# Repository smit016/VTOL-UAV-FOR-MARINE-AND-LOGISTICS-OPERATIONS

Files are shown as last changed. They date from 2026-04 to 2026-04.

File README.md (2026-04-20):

This report presents the conceptual design and preliminary analysis of a hybrid Vertical
Take-Off and Landing (VTOL) Unmanned Aerial Vehicle (UAV) intended for transportation of
time-sensitive payloads in remote and infrastructure-limited environments. The UAV is
designed to carry a payload of 3–5 kg over a range of up to 100 km while maintaining high
operational flexibility, energy efficiency, and autonomous capability.
A hybrid VTOL configuration is selected to combine the advantages of vertical lift for take-off
and landing with efficient fixed-wing cruise performance. The design process follows a
systematic conceptual design methodology based on the approach proposed by Daniel
Raymer. Key design parameters such as weight estimation, thrust requirements, power
loading, and tail sizing are determined analytically. The design is further validated through
aerodynamic analysis (CFD).

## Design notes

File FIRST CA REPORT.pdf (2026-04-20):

## Conceptual Design and Aerodynamic Analysis of a Hybrid VTOL UAV for Long-Endurance Payload Delivery

Submitted by-:
Smit Panchal
12303271

### ABSTRACT

This report presents the conceptual design and preliminary analysis of a hybrid Vertical Take-Off and Landing (VTOL) Unmanned Aerial Vehicle (UAV) intended for transportation of time-sensitive payloads in remote and infrastructure-limited environments. The UAV is designed to carry a payload of 3–5 kg over a range of up to 100 km while maintaining high operational flexibility, energy efficiency, and autonomous capability.

A hybrid VTOL configuration is selected to combine the advantages of vertical lift for take-off and landing with efficient fixed-wing cruise performance. The design process follows a systematic conceptual design methodology based on the approach proposed by Daniel Raymer. Key design parameters such as weight estimation, thrust requirements, power loading, and tail sizing are determined analytically. The design is further validated through aerodynamic analysis (CFD).

### 1. Introduction

Unmanned Aerial Vehicles (UAVs) have become essential in applications such as surveillance, logistics, agriculture, and disaster response. Based on configuration and flight mechanics, UAVs are broadly classified into:

### 1.1 Types of UAVs

### 1. Fixed-Wing UAVs

- High aerodynamic efficiency
- Long endurance and range
- Require runway or launch systems

### 2. Rotary-Wing UAVs (Multirotors)

- Vertical take-off and landing capability
- Excellent maneuverability
- Limited endurance due to high power consumption

### 3. Hybrid VTOL UAVs

- Combine vertical lift and fixed-wing cruise
- Capable of operating in confined areas
- Offer improved range compared to multirotors

### 3. Problem Statement

The objective is to design a UAV capable of:

- Carrying 3–5 kg payload
- Operating over ~100 km range
- Functioning in remote or infrastructure-limited environments
- Ensuring high reliability and energy efficiency

Why VTOL?

- Eliminates need for runway → critical in remote areas
- Enables deployment in constrained environments
- Improves mission flexibility

Why Hybrid VTOL Configuration?

Pure multirotors are inefficient for long-range missions, while fixed-wing UAVs lack operational flexibility. A hybrid VTOL system provides:

- Efficient cruise (wing-borne lift reduces power demand)
- Vertical take-off capability
- Better endurance compared to multirotors

Why Twin Boom + Pusher Configuration?

- Allows unobstructed airflow for rear propeller
- Provides structural support for tail
- Facilitates payload placement near CG
- Improves stability and control

### 3. METHODOLOGY

Approach

The UAV is designed using a conceptual design methodology based on Daniel Raymer. The design follows a sequential and constraint-based approach, where primary parameters such as weight, wing loading, and thrust requirements are determined from mission requirements.

The procedure adopted is as follows:

1. Estimation of Maximum Take-Off Weight (MTOW) using component build-up method
2. Determination of thrust requirement based on VTOL condition
3. Wing sizing based on stall speed constraint
4. Determination of geometric parameters (span, chord, aspect ratio)
5. Tail sizing using volume coefficient method
6. Estimation of cruise performance and Reynolds number

All calculations were implemented using a Python-based parametric tool to ensure consistency and enable rapid iteration.

WEIGHT AND THRUST ESTIMATION

The MTOW is estimated using a component build-up approach, where known subsystem weights are summed and adjusted using a structural weight fraction. Thrust is determined based on a thrust-to-weight ratio of 2 to ensure safe hover and control during VTOL operation.

Component Category | Notation | Design Value (kg) | % of MTOW
Payload Capacity | W_payload | 5.00 | 28.4%
Energy Source (Battery) | W_batt | 4.00 | 22.8%
Structure & Airframe | W_struct | 5.98 | 34.0%

Thrust Requirements

Propulsion System | W_prop | 1.10 | 6.3%
Avionics & Electronics | W_sys | 1.50 | 8.5%
Maximum Take-Off Weight | MTOW | 17.58 | 100%
Design Parameter | Notation | Unit | Value
Total Weight (Force) | W | N | 172.42
Thrust-to-Weight Ratio | T/W | - | 2.0
Total Thrust Required | T_req | N | 344.84
Number of Motors | N | - | 5
Thrust per Motor | T_motor | N | 68.97

WING SIZING

The wing is sized based on the stall speed constraint to ensure adequate lift generation during low-speed flight and VTOL transition. Wing loading is determined from the lift equation at stall condition, and the wing area is calculated from the estimated weight.

Geometric parameters such as wingspan, chord distribution, and mean aerodynamic chord are obtained using the selected aspect ratio and taper ratio. Cruise velocity is determined from lift equilibrium, and Reynolds number is evaluated to ensure suitability of airfoil selection.

A relatively low wing loading is obtained, which improves low-speed performance and transition stability.

Design Parameter | Symbol | Unit | Value
Design Mass | m | kg | 17.00
Total Weight | W | N | 166.77
Stall Velocity | V_stall | m/s | 14.00
Max Lift Coefficient | C_L_max | - | 1.4
Wing Loading | W/S | N/m² | 168.07
Wing Area | S | m² | 0.992

Aspect Ratio | AR | - | 8.2
Wingspan | b | m | 2.85
Taper Ratio | λ | - | 0.45
Root Chord | c_root | m | 0.480
Tip Chord | c_tip | m | 0.216
Mean Aerodynamic Chord | MAC | m | 0.365
Cruise Lift Coefficient | C_L | - | 0.6
Cruise Velocity | V_cruise | m/s | 21.39
Reynolds Number | Re | - | 5.28 × 10⁵

TAIL SIZING

The tail surfaces are sized using the volume coefficient method to ensure adequate longitudinal and directional stability. The horizontal tail volume coefficient governs pitch stability, while the vertical tail volume coefficient governs yaw stability.

The updated wing geometry is used to maintain consistency in design. A twin-boom configuration is adopted, resulting in two vertical stabilizers. Tail geometry is determined using selected aspect ratios, and control surface dimensions are estimated as a fraction of tail chord.

Horizontal Tail

Parameter | Value
Wing Area (Sw) | 0.992 m2
Mean Chord (c) | 0.365 m
Tail Arm (lt) | 0.95 m
Volume Coefficient (Vh) | 0.6
Horizontal Tail Area (Sh) | 0.229 m2
Aspect Ratio (ARh) | 4.0
Span (bh) | 0.958 m

Chord (ch) | 0.239 m

Vertical Tail

Parameter | Value
Wing Area (Sw) | 0.992 m²
Wingspan (b) | 2.85 m
Tail Arm (lt) | 0.95 m
Volume Coefficient (Vv) | 0.05
Total Vertical Tail Area (Sv) | 0.149 m²
Configuration | Twin Tail
Area per Tail | 0.074 m²

Aspect Ratio (ARv) | 1.5
Height (bv) | 0.334 m
Chord (cv) | 0.222 m

Control Surfaces

Surface | Range
Elevator Chord | 0.060 – 0.072 m
Rudder Chord | 0.067 – 0.089 m

FUSELAGE SIZING, CG AND STABILITY ANALYSIS

Design Approach

The fuselage is designed based on payload integration, propulsion layout, and stability requirements. The length is governed by the required tail moment arm, while internal layout is optimized to achieve the desired center of gravity (CG).

A mass–moment balance approach is used to determine CG location, and stability is assessed using static margin and neutral point estimation, following conceptual design practices from Daniel Raymer.

Fuselage Length Determination

The fuselage length is defined by the tail arm requirement:

Lfus≈xLE + lt

Parameter | Value
Wing LE location (x_LE) | 0.40 m
Tail Arm (lt) | 1.00 m
Fuselage Length | 1.40 m

Design Insight

- Length is driven by stability (tail arm) and payload packaging
- Ensures sufficient moment arm for tail effectiveness

Mean Aerodynamic Chord (MAC)

Parameter | Value
Root Chord | 0.416 m
Tip Chord | 0.163 m
Taper Ratio | 0.39
MAC | 0.30 m

Target CG Location

For stable aircraft:

Parameter | Value
CG Location Formula | xCG = xLE + (0.25 – 0.35) * MAC
CG Range (xCG) | 0.475 – 0.505 m

Mass Distribution

Component | Mass (kg) | Position (mm)
Payload | 5.0 | 400
Avionics | 1.5 | 450
Structure | 5.9 | 8490
Propulsion | 1.1 | 1400
Battery | 4.0 | Variable

CG Calculation ( Xcg =∑(mixi) / ∑mi )

Parameter | Value
Total Mass | 17.576 kg
Fixed Moment | 7145 kg·mm
Battery Position | ~370 mm from nose
Final CG | 490 mm

CG Shift Analysis

Condition | CG | Observation
With Payload | 490 mm | Stable
Without Payload | 526 mm | Aft shift

Interpretation

- CG shifts rearward by ~36 mm
- Reduces stability margin
- Must be accounted for in operation/design

At the conceptual design stage, the center of gravity (CG) and stability characteristics are estimated based on assumed mass distribution and geometric parameters. These estimates are used primarily for layout validation and component placement.

A preliminary neutral point and static margin can be estimated using standard relations; however, these values are subject to change after aerodynamic and structural refinement.

Preliminary Observation

- The CG is positioned at approximately 30% of MAC, which lies within the typical stable range for conventional aircraft configurations
- Tail volume coefficients are selected to ensure adequate stability margins

The current CG and stability assessment are preliminary and intended for conceptual design validation only.

Final CG location, neutral point, and static margin will be determined after:

- Detailed aerodynamic analysis (CFD)
- Structural design and weight distribution refinement
- Final component integration

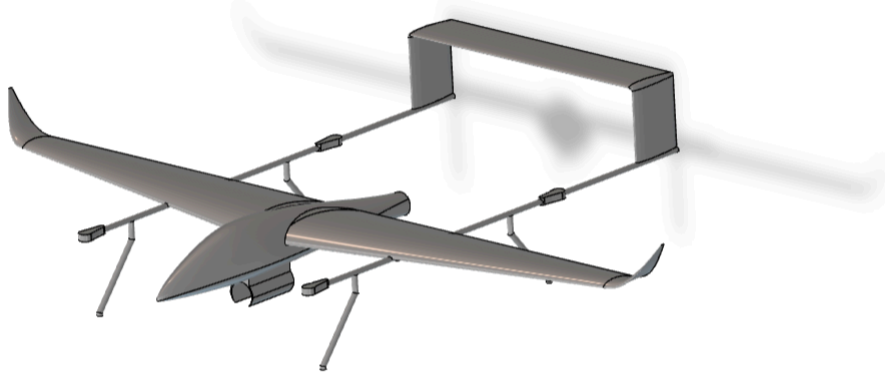
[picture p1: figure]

### 4. CFD ANALYSIS AND AERODYNAMIC VALIDATION

Objective

The Computational Fluid Dynamics (CFD) analysis is performed to evaluate the aerodynamic performance of the UAV, specifically:

- Lift generation capability
- Drag characteristics
- Flow behavior over wing and fuselage
- Validation of conceptual design assumptions

Geometry Used for Analysis

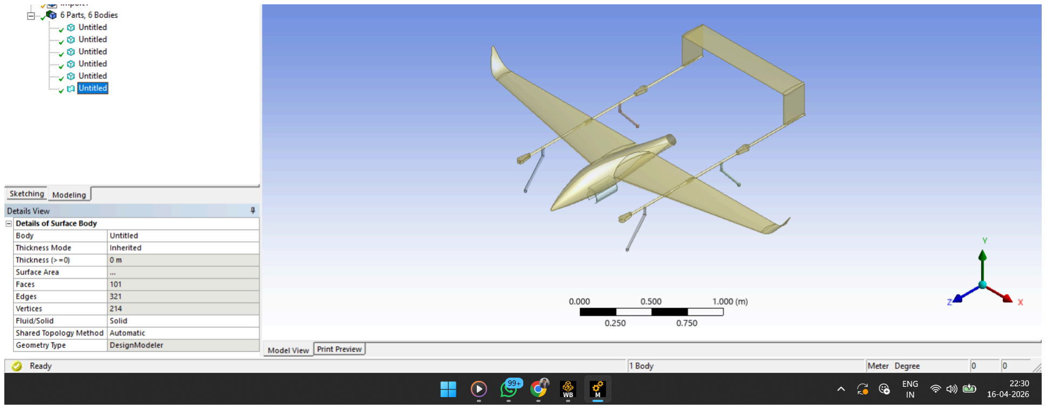
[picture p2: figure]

The CFD model consists of:

- Wing (main lifting surface)
- Fuselage
- Twin boom tail configuration
- Horizontal and vertical stabilizers

Small geometric details were simplified to reduce computational cost while preserving aerodynamic characteristics.

## Computational Domain

The domain is designed to minimize boundary interference effects and ensure accurate flow development.

ASSUMPTIONS

Parameter | Value
Inlet distance | ~5–7 chord lengths
Outlet distance | ~10–15 chord lengths
Lateral boundaries | ≥ 5 chord lengths
Flow type | External, incompressible

Mesh Generation

Approach

- Unstructured tetrahedral mesh used
- Local refinement near:
- Wing leading edge
- Trailing edge
- Fuselage
- Boundary layer resolved using inflation layers

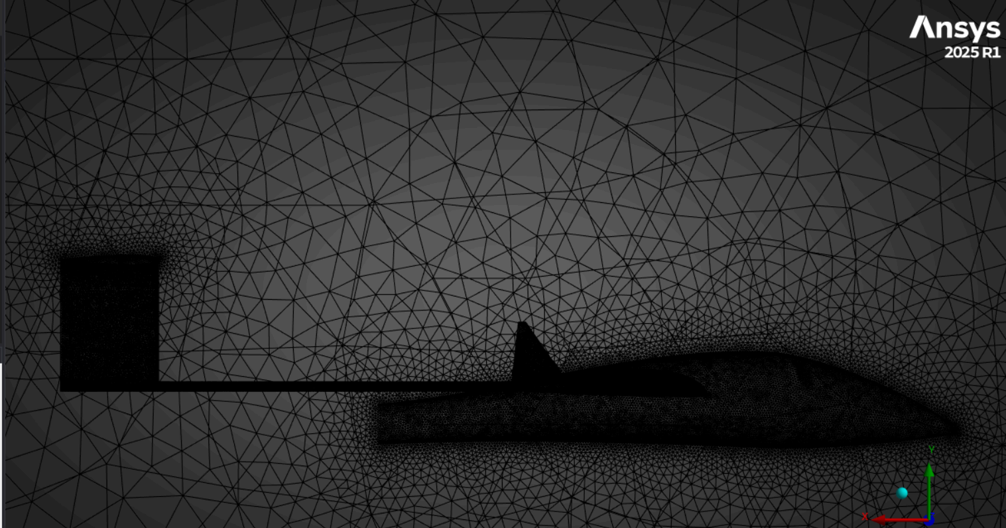
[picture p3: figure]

Boundary Layer Resolution

First layer height calculation:

Parameter | Value
Reynolds Number | 5.14 x 10^5
Skin Friction Coefficient | 0.00397
Wall Shear Stress | 1.52 Pa
Friction Velocity | 1.11 m/s

First Layer Height | 0.013 mm
Target (y+) | ~1

## Interpretation

- y+≈1 → resolves viscous sublayer
- Suitable for k-ω SST model
- High-quality boundary layer capture

Solver Setup

Parameter | Value
Software | ANSYS Fluent
Solver Type | Pressure-based
Flow | Steady
Regime | Incompressible

Turbulence Model | K-omega SST
Velocity (Inlet) | 25 m/s
Reynolds Number | ~5 x 10^5

## Why k-ω SST?

- Better near-wall prediction
- Handles adverse pressure gradients
- Suitable for low Reynolds UAV flows

Boundary Conditions

Boundary | Type
Inlet | Velocity inlet (25 m/s)
Outlet | Pressure outlet
Walls | No-slip condition
Far-field | Symmetry / pressure far-field

Results

Pressure Distribution

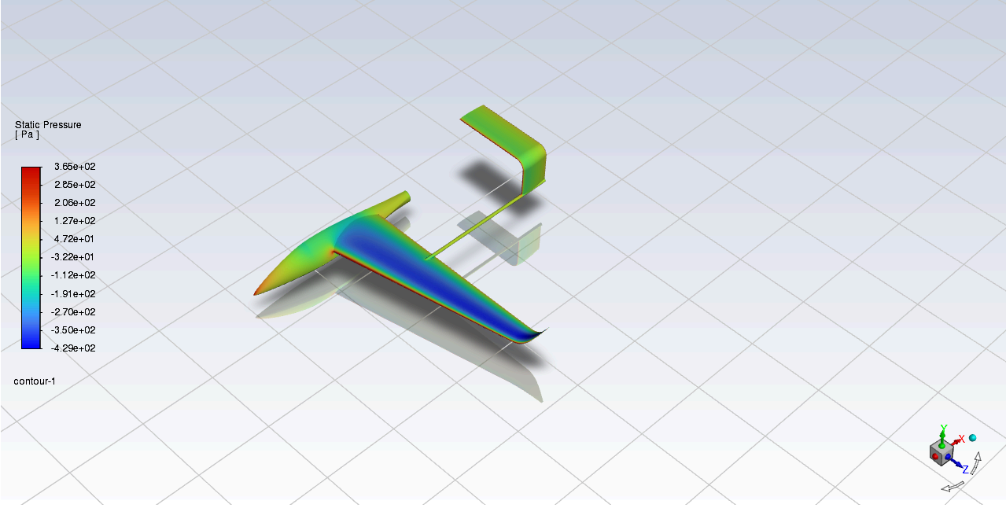
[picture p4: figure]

Observation:

- High pressure on lower surface
- Low pressure (suction) on upper surface
- Strong lift generation confirmed.
Parameter | Value
Lift (L) | 200 N
Drag (D) | 11 N
Lift-to-Drag Ratio (L/D) | 18.18

### 5. CONCLUSION

The present work focused on the conceptual design and aerodynamic evaluation of a hybrid VTOL UAV intended for long-endurance payload delivery in infrastructure-limited environments. The design process followed a structured methodology based on established aircraft design principles, ensuring logical progression from mission requirements to aerodynamic validation.

The UAV configuration, consisting of a high-aspect-ratio wing, twin-boom tail, and pusher propulsion system, was selected to balance vertical take-off capability with efficient forward flight. Weight estimation and thrust sizing confirmed the feasibility of VTOL operation, while wing sizing based on stall constraints resulted in a low wing loading configuration, enhancing low-speed performance and transition stability.

CFD analysis provided validation of the aerodynamic design. The results indicated that the UAV is capable of generating sufficient lift (≈200 N) to sustain flight at the design condition, exceeding the estimated weight (~170 N). The computed drag (~11 N) remains within acceptable limits for this class of UAV.

Aerodynamic Efficiency Assessment

The aerodynamic efficiency of the UAV, defined by the lift-to-drag ratio L/D ≈ 18, is a key outcome of this study.The designed UAV achieves an aerodynamic efficiency comparable to fixed-wing aircraft and significantly higher than typical VTOL systems.

Aircraft Type | Typical L/D
Multirotor UAV | 3–6
VTOL Hybrid UAV | 8–15
Fixed-wing UAV | 12–20
Gliders | 30+

Reasons for High Aerodynamic Efficiency

The favorable aerodynamic performance can be attributed to the following design choices:

### 1. Wing Design

- Aspect ratio ≈ 8.2 reduces induced drag
- Large wing area lowers wing loading
- Operation at moderate lift coefficient ensures efficient lift generation

### 2. Low Reynolds Number Optimization

- Operating at Re∼5×105Re \sim 5 \times 10^5Re∼5×105, suitable for small UAVs
- Airfoil and sizing aligned with low-speed aerodynamic behavior
- Avoidance of excessive drag rise

### 3. Configuration Selection

- Twin boom layout minimizes interference effects
- Pusher configuration ensures clean flow over the wing
- High-wing arrangement improves aerodynamic stability

### 4. CFD Flow Characteristics

- Smooth pressure distribution observed
- No significant flow separation detected
- Efficient lift generation across the wing span

Engineering Significance

- High aerodynamic efficiency directly contributes to increased endurance
- Reduced drag leads to lower power consumption in cruise
- The design demonstrates strong potential for long-range UAV operations

Limitations and Realistic Considerations

While the CFD results indicate strong aerodynamic performance, the obtained efficiency is expected to be slightly optimistic due to modeling simplifications.

“The aerodynamic efficiency obtained from CFD is considered optimistic, as propeller effects, transition modeling, and structural surface roughness are not included in the present analysis.”

Key limitations include:

- Absence of propeller–flow interaction
- No transition modeling (laminar to turbulent)
- Idealized surface conditions and Lack of full-system drag contributions

FUTURE SCOPE

The present work establishes a conceptual design and preliminary aerodynamic validation of the hybrid VTOL UAV. Further refinement is required to enhance accuracy and enable practical implementation.

Future work will focus on incorporating propulsion–airframe interaction, including propeller wake effects and evaluation of VTOL efficiency through figure of merit analysis. Detailed flow-field studies will be conducted to analyze circulation distribution, vortex formation, and wake behavior for improved aerodynamic understanding.

Advanced aerodynamic investigations will include transition modeling, mesh independence studies, and drag breakdown, enabling more accurate performance prediction. A comprehensive flight performance analysis will be carried out, including power required, endurance, range, and climb characteristics.

Further, a complete flight mechanics and stability analysis will be performed, involving refined neutral point estimation, static margin evaluation, and dynamic stability modes. Basic control system modeling, particularly for pitch dynamics and elevator deflection, will also be developed to support controllability and future autopilot integration.

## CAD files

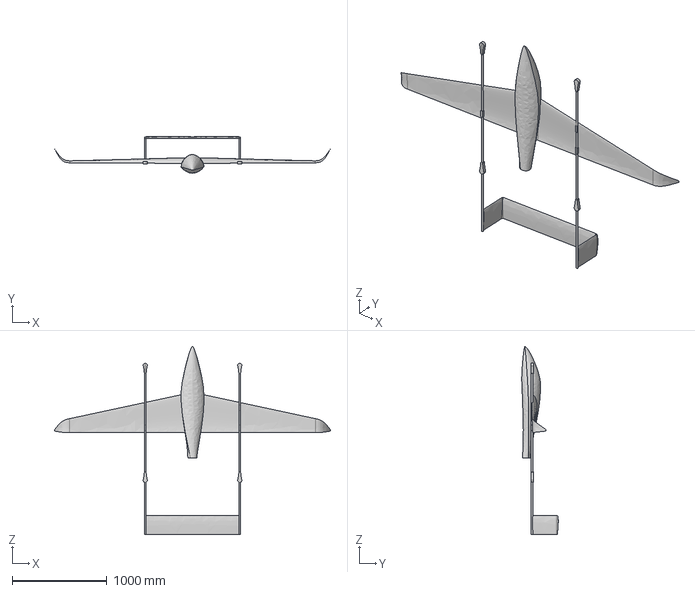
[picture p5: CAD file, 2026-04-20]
vyomvtol2.step
2920.3 x 386.9 x 1990.6 mm

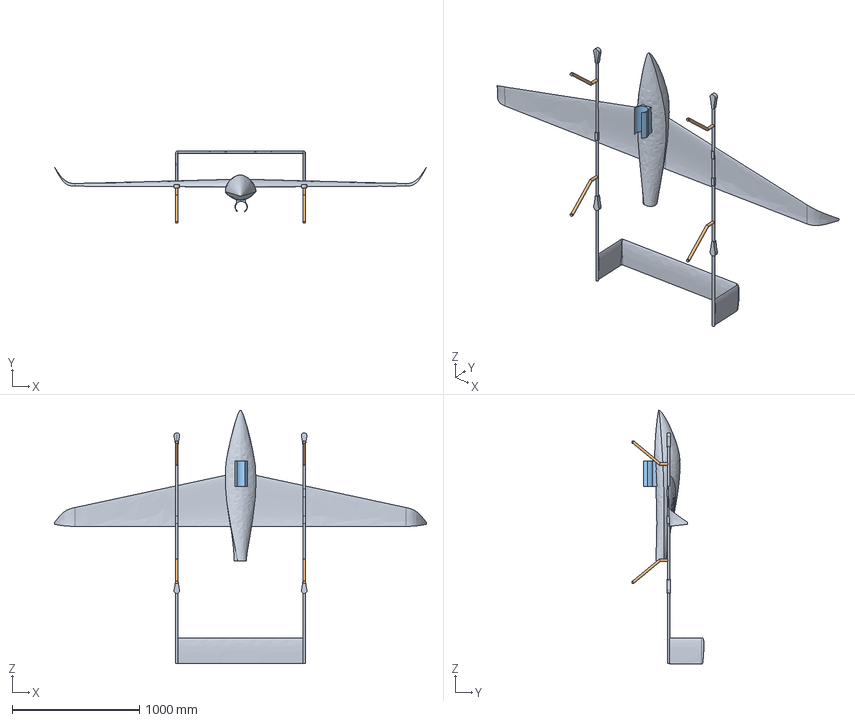
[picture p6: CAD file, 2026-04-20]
vyomvtoluav3.step
2920.3 x 565.0 x 1990.6 mm

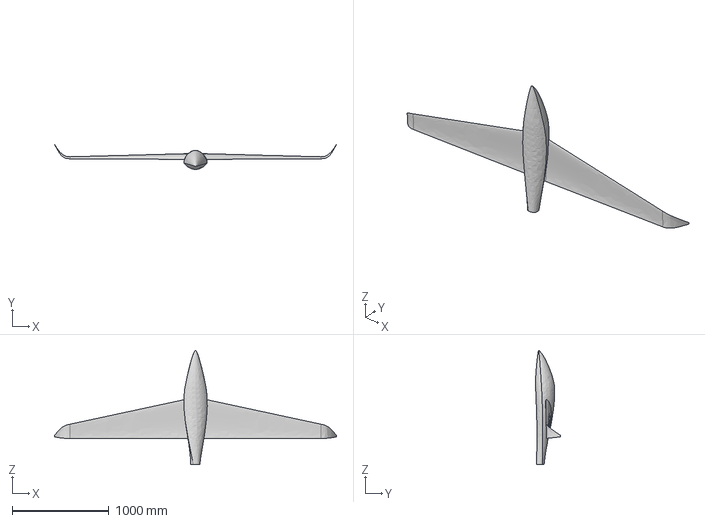
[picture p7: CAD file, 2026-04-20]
Vyomvtoluav.step
2920.3 x 258.8 x 1182.5 mm

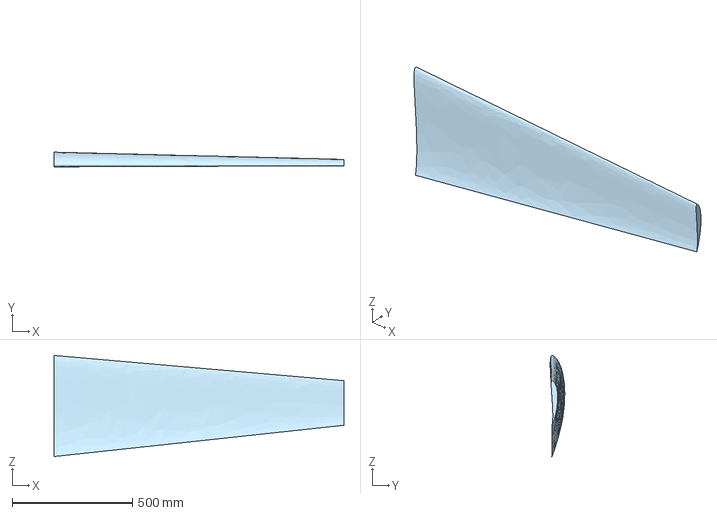
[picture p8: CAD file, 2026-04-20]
wing.step
1205.0 x 61.0 x 420.0 mm

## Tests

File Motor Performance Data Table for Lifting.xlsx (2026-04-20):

Throttle (%) | Thrust (g) | Current (A) | Power In (W) | Speed (RPM) | Efficiency (g/W) | Torque (N·m) | Power Out (W)
33% | 1654 | 2.5 | 116.5 | 1307 | 14.2 | 0.64 | 99
35% | 1812 | 2.8 | 130.3 | 1364 | 13.9 | 0.69 | 110.7
37% | 1996 | 3.2 | 147.2 | 1428 | 13.6 | 0.76 | 125.1
39% | 2202 | 3.6 | 167.3 | 1498 | 13.2 | 0.84 | 142.2
42% | 2545 | 4.4 | 203 | 1609 | 12.5 | 0.97 | 172.5
45% | 2918 | 5.3 | 245.1 | 1723 | 11.9 | 1.11 | 208.3
48% | 3313 | 6.4 | 293.1 | 1836 | 11.3 | 1.25 | 249.1
51% | 3722 | 7.5 | 346.3 | 1946 | 10.7 | 1.4 | 294.3
54% | 4141 | 8.8 | 404.2 | 2050 | 10.2 | 1.56 | 343.5
57% | 4562 | 10.1 | 466.2 | 2150 | 9.8 | 1.72 | 396.2
60% | 4985 | 11.6 | 531.9 | 2243 | 9.4 | 1.87 | 452.1
63% | 5406 | 13.1 | 601.2 | 2332 | 9 | 2.03 | 511
66% | 5825 | 14.6 | 674 | 2417 | 8.6 | 2.18 | 572.9
69% | 6243 | 16.3 | 750.4 | 2498 | 8.3 | 2.34 | 637.8
72% | 6661 | 18 | 830.9 | 2579 | 8 | 2.49 | 706.3
75% | 7082 | 19.9 | 916.2 | 2658 | 7.7 | 2.65 | 778.7
78% | 7510 | 21.9 | 1007.2 | 2738 | 7.5 | 2.81 | 856.1
81% | 7950 | 24 | 1105.4 | 2820 | 7.2 | 2.98 | 939.6
84% | 8408 | 26.3 | 1212.5 | 2904 | 6.9 | 3.15 | 1030.6
87% | 8890 | 28.9 | 1330.5 | 2991 | 6.7 | 3.34 | 1130.9
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
